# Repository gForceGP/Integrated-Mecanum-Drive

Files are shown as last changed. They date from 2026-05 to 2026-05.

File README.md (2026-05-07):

# Integrated Mecanum Drive (IMD)

**This modification for GoBILDA mecanum wheels allows for direct-drive motor integration within the wheel assembly.**

## Why Build This?

<table>
  <tr>
    <td valign="top">
      Standard mecanum drives often require bulky chain, belt, or gear-driven setups inside the robot chassis. This modification integrates the motor directly into the wheel hub, offering:<br><br>
      <ul>
        <li><b>Maximized Internal Space:</b> Frees up chassis space for electronics and mechanisms.</li>
        <li><b>Rapid Serviceability:</b> Self-contained design allows for quick drive unit swaps, eliminating the need for main chassis disassembly.</li>
        <li><b>Zero Backlash:</b> Direct-drive eliminates the slop inherent in chain/belt reductions.</li>
        <li><b>Fewer Points of Failure:</b> Eliminates external belts, chains, and pulleys, reducing the overall part count and removing the need for regular tensioning.</li>
      </ul>
    </td>
    <td valign="top">
      Classic vs IMD Design Comparison
    </td>
  </tr>
</table>

CAD model 1

<p align="center">
  Real life model 1
  Real life model 2
</p>

## Basic Characteristics
* **Base Wheel:** goBILDA GripForce™ Mecanum Ø104mm Wheel Set (40A Durometer).
* **Propulsion:** goBILDA 5203 Series Yellow Jacket Planetary Gear Motor (435 RPM).
* **Structural Frame:** Custom 3D printed motor mounts and precision shaft spacers.
* **Power Transfer:** Direct-drive (1:1 ratio) utilizing the heavy-duty 8mm REX™ shaft ecosystem.
* **Estimated Performance:** Theoretical top speed of ~2.3 m/s (with 435 RPM motor).

## CAD Model & Configurable Assembly
The model was designed in Onshape. You can view, interact with, and export the configurable assembly (along with the complete BOM) directly from your browser here:

**[Open IMD in Onshape](https://cad.onshape.com/documents/8f367a5f6d2e58f122acd332/w/d92d81f4d48a76e09882f61c/e/26f170c9af19b0b97c028cc4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)**

## Example Applications (Drivebases)
To help you integrate these modules into your robot, I have included CAD models for two example drivebases in the `Drivebase_Examples` folder:
1. **goBILDA U-Channel Chassis:** Demonstrates how to mount the modules using standard goBILDA structural components.         
**[View goBILDA U-Channel Chassis in Onshape](https://cad.onshape.com/documents/8f367a5f6d2e58f122acd332/w/d92d81f4d48a76e09882f61c/e/bcba49029b301266226bcfa4)**
2. **Custom Plate Chassis:** Demonstrates how to mount the modules using custom-machined plates and standoffs for a more compact footprint.
**[View Custom Plate Chassis in Onshape](https://cad.onshape.com/documents/8f367a5f6d2e58f122acd332/w/d92d81f4d48a76e09882f61c/e/f1c13dd2a2df37d270d419c0)**

<p align="center">
  goBILDA Chassis CAD model 1
  Custom Chassis CAD model 1
</p>

## 3D Printing Recommendations
These custom parts handle the structural weight of the robot and the motor's torque, so part strength is critical. 

* **Recommended Setup (Tested):** Nylon (PA) with 4+ perimeters/walls and 50% infill (Gyroid or Cubic). 
* **Alternative Materials:** PETG, ABS, ASA, or Polycarbonate.
* **A Note on PLA:** While standard PLA is generally not recommended for competition robotics due to impact brittleness, prototype testing proved that 100% infill PLA successfully handled up to an 80kg static load without failing.

## Bill of Materials (BOM)
To build **one** complete wheel module, you will need the following parts:

| Item | Quantity | Name |
| :--- | :--- | :--- |
| 1 | 1 | 104mm Mecanum Wheel (Ø104mm, 40A Durometer Rollers) 3625-0202-0104 [`goBILDA`](https://www.gobilda.com/gripforce-mecanum-wheel-set-o104mm-40a-durometer-rollers/) |
| 2 | 1 | 1309 Series Sonic Hub (8mm REX® Bore) 1309-0016-4008 [`goBILDA`](https://www.gobilda.com/1309-series-sonic-hub-8mm-rex-bore/) |
| 3 | 1 | 1401 Series 2-Side, 2-Post Clamping Mount (43mm Width, 36mm Bore) [`goBILDA`](https://www.gobilda.com/1401-series-2-side-2-post-clamping-mount-43mm-width-36mm-bore/) |
| 4 | 1 | 1611 Series Flanged Ball Bearing (8mm REX ID x 14mm OD, 5mm Thickness) 1611-0514-4008 [`goBILDA`](https://www.gobilda.com/1611-series-flanged-ball-bearing-8mm-rex-id-x-14mm-od-5mm-thickness-2-pack/) |
| 5 | 1 | 5203 Series Yellow Jacket Planetary Gear Motor (13.7:1 Ratio, 24mm Length 8mm REX Shaft, 435 RPM, 3.3 - 5V Encoder) 5203-2402-0014 [`goBILDA`](https://www.gobilda.com/5203-series-yellow-jacket-planetary-gear-motor-13-7-1-ratio-24mm-length-8mm-rex-shaft-435-rpm-3-3-5v-encoder/) |
| 6 | 4 | Hex nut grade A & B M4x0.7 |
| 7 | 4 | Hex socket countersunk head screw M4x0.7 x 12 |
| 8 | 1 | Hex socket head cap screw M4x0.70 x 14 |
| 9 | 4 | Hex socket head cap screw M4x0.70 x 30 x 20 |
| 10 | 1 | Motor mount [`3d Printed`](https://cad.onshape.com/documents/8f367a5f6d2e58f122acd332/w/d92d81f4d48a76e09882f61c/e/5f703f59c31e528baac41de4)|
| 11 | 1 | Shaft spacer [`3d Printed`](https://cad.onshape.com/documents/8f367a5f6d2e58f122acd332/w/d92d81f4d48a76e09882f61c/e/1af7b1871e39168f8384e6b7)|
| 12 | 1 | Wheel Spacer [`3d Printed`](https://cad.onshape.com/documents/8f367a5f6d2e58f122acd332/w/d92d81f4d48a76e09882f61c/e/5f703f59c31e528baac41de4)|

## Assembly instructions
Integrated Mecanum Drive (IMD) Assembly instructions

Integrated Mecanum Drive (IMD)  © 2026 by Gabriel Pieniek is licensed under CC BY-NC-SA 4.0. To view a copy of this license, visit https://creativecommons.org/licenses/by-nc-sa/4.0/

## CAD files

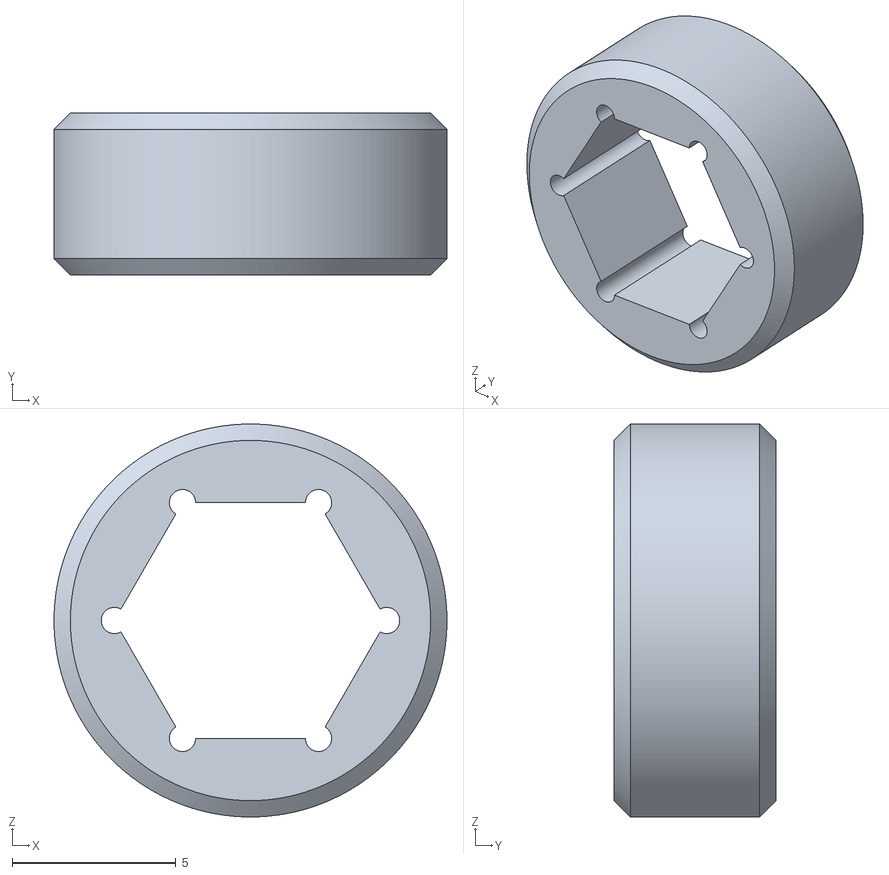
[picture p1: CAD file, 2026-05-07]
STLs_for_3D_Printing/Shaft spacer.stl
12.0 x 4.95 x 12.0

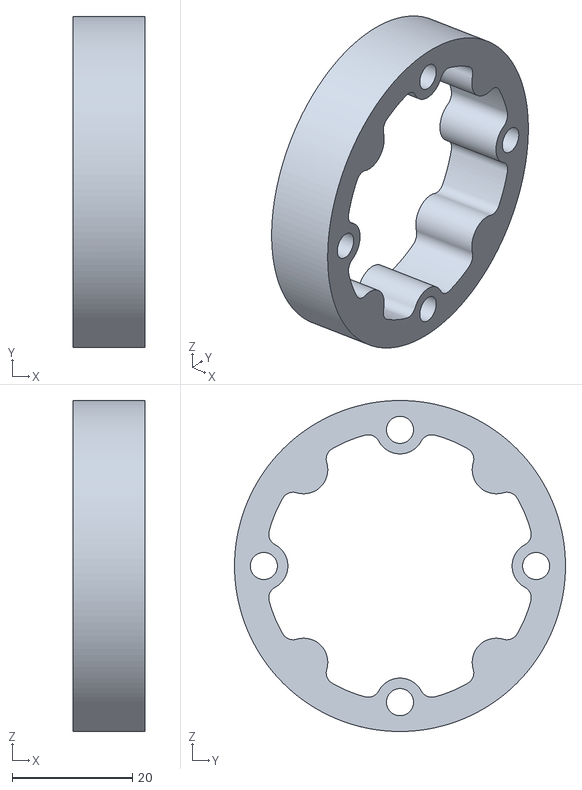
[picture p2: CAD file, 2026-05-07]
STLs_for_3D_Printing/Wheel Spacer.stl
12.0 x 55.0 x 55.0

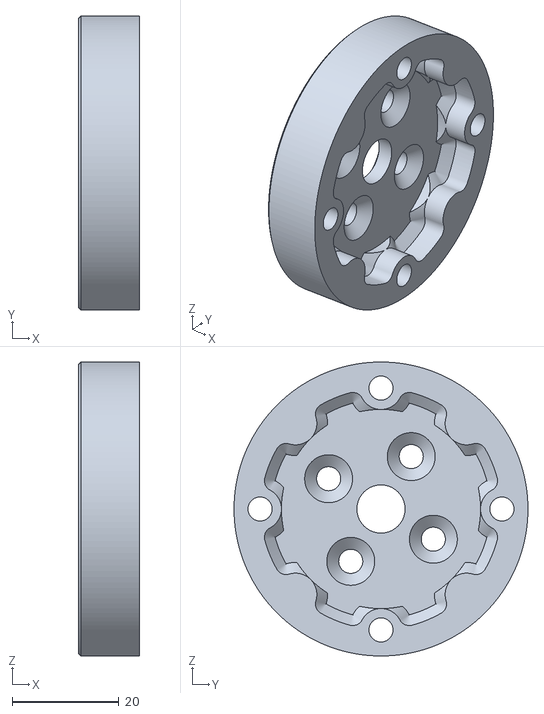
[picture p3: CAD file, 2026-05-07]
STLs_for_3D_Printing/Motor mount.stl
11.5 x 55.0 x 55.0
